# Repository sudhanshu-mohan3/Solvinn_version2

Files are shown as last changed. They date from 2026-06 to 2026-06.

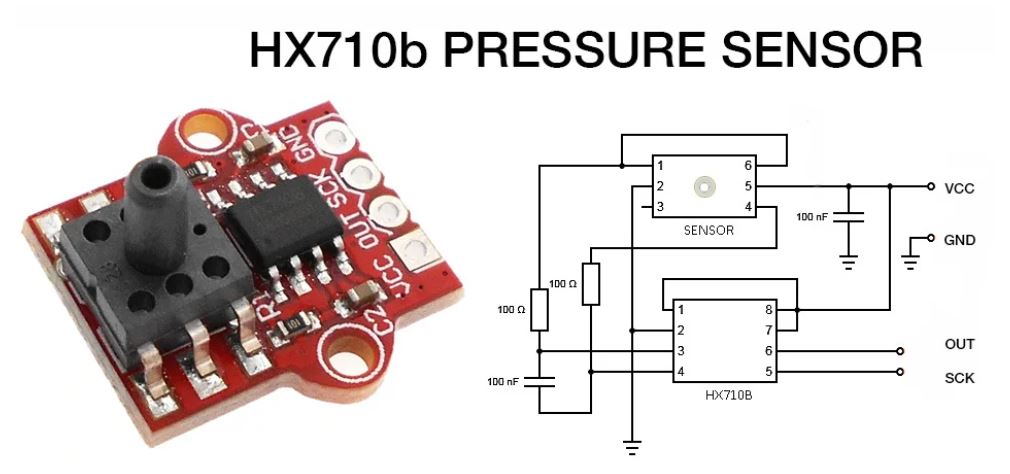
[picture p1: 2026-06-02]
hardware/Kicad/Main_PCB/Solventech_Controller/pressure-sensor-hx710b-1.snapshot.3/HX710B_2.JPG

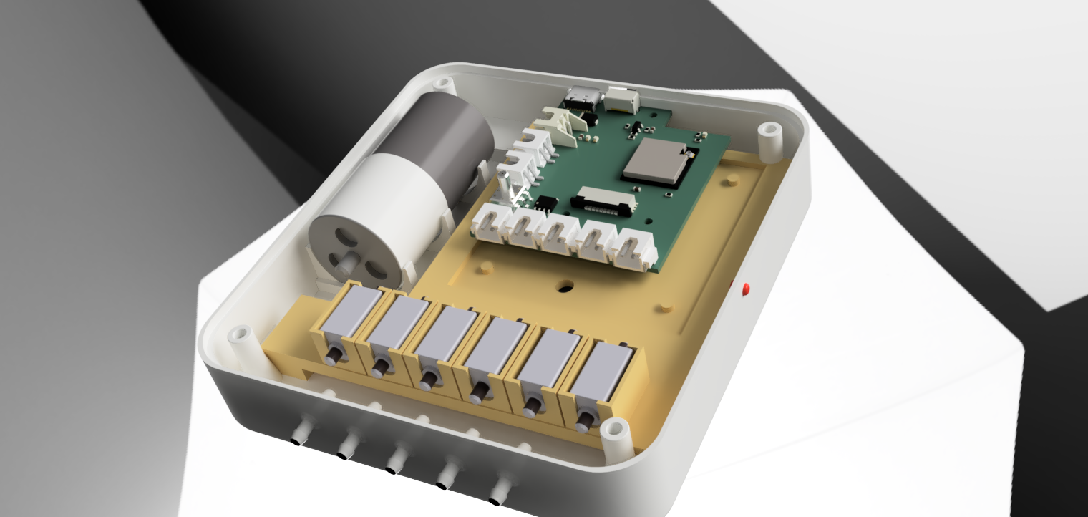
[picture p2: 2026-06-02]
hardware/Kicad/Main_PCB/Solventech_Controller/VervoFlo_2025-May-25_04-00-59PM-000_CustomizedView23459977114_png.png

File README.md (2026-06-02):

# VerveFlo

Pneumatic Compression Therapy Device firmware
ESP32-S3 · Arduino IDE

## Hardware
- ESP32-S3 Dev Module
- SH1106 OLED 128x64 (I2C)
- HX710B Pressure Sensor
- 5x Fill Solenoid Valves + 1x Release Valve (normally-open)
- 5V DC Pump Motor
- 2S 18650 Li-Ion Battery

## Pin Map
| Component | GPIO |
|---|---|
| Fill Valve 1 | 26 |
| Fill Valve 2 | 47 |
| Fill Valve 3 | 39 |
| Fill Valve 4 | 40 |
| Fill Valve 5 | 41 |
| Release Valve  | 42 |
| Pump Motor | 21 |
| HX710B Dout | 34 |
| HX710B SCK | 33 |
| LED | 3 |
| Battery ADC | 15 |
| BTN Start | 35 |
| BTN Mode | 36 |
| BTN Pressure | 37 |
| BTN Time | 48 |

## Libraries Required
- U8g2 by olikraus
- Q2HX711 by bogde (Queuetue_HX711_Library)
- WiFi / WebServer / DNSServer / Preferences — built into ESP32 core

## Board Settings
- Board: ESP32S3 Dev Module
- USB CDC On Boot: Enabled
- Partition: Default 4MB with spiffs

## Files
| File | Purpose |
|---|---|
| verveflo.ino | Main firmware — flash this |
| verveflo_hwtest.ino | Hardware test — no libraries needed |
| verveflo_pressure_cal.ino | Pressure sensor calibration |
| verveflo_valve_test.ino | Valve test with OLED |

## First Time Setup
1. Flash verveflo.ino
2. Connect phone to WiFi hotspot: VerveFlo-Setup
3. Open 192.168.4.1 → enter your WiFi password
4. Open browser → http://[device IP]
5. Serial: type zero at atmosphere
6. Serial: type selftest to verify hardware

## Serial Monitor
115200 baud · Newline line ending
Type help for full command list

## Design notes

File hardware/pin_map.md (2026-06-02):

# VerveFlo — Pin Map

Board: **ESP32-S3 Dev Module**
Pins verified against the hardware sheet (firmware v3.1).

## Valves

Valve array index order in firmware: `VALVE_PINS[6] = { 26, 47, 39, 40, 41, 42 }`

| Index | Valve | GPIO | Type | Notes |
|---|---|---|---|---|
| 0 | Fill Valve 1 | 26 | Normally-closed | Cuff 1 |
| 1 | Fill Valve 2 | 47 | Normally-closed | Cuff 2 |
| 2 | Fill Valve 3 | 39 | Normally-closed | Cuff 3 |
| 3 | Fill Valve 4 | 40 | Normally-closed | Cuff 4 |
| 4 | Fill Valve 5 | 41 | Normally-closed | Cuff 5 |
| 5 | Release Valve  | 42 | **Normally-open** | Logic inverted — energize (HIGH) to hold pressure, de-energize (LOW) to vent |

## Pump

| Component  | GPIO | Notes |
|---|---|---|
| Pump motor | 21 | Soft start via `analogWrite()` |

## Pressure sensor (HX710B)

| Signal | GPIO | Notes |
|---|---|---|
| Dout | 34 | Data out from sensor |
| SCK / CLK  | 33 | Clock |

Calibration (v3.1):
- `CALIB_M = +0.00000625` (raw increases with pressure — positive)
- `CALIB_B = 0.0`
- `CALIB_ZERO = 8388000` (atmosphere reference, re-zero with `zero` serial command)
- Overflow filter: discard raw > 16000000 (HX710B 2^24 saturation on fast release)

## Display

| Component | Interface | Notes |
|---|---|---|
| SH1106 OLED 128x64 | I2C (HW) | U8g2 library |

## Buttons (active LOW)

| Button | GPIO | Function |
|---|---|---|
| BTN Start | 35 | Play / start session |
| BTN Mode | 36 | Cycle mode |
| BTN Pressure | 37 | Cycle pressure level |
| BTN Time | 48 | Cycle session time |

## Misc

| Component | GPIO | Notes |
|---|---|---|
| LED | 3 | Status LED |
| Battery ADC | 15 | Voltage divider — battery % |

## Power

- 2S 18650 Li-Ion battery
- 5V rail for pump + valves

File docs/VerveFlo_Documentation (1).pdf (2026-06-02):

Solvin Medical Devices — VerveFlo v3.0 — Confidential

# VerveFlo

## Pneumatic Compression Therapy Device

### Complete Technical & User Documentation | v3.0

Platform | ESP32-S3 · Arduino IDE
Firmware | verveflo.ino — Single file, all-in-one
Display | SH1106 OLED 128x64 I2C
Sensor | HX710B Pressure Sensor
WiFi | AP Captive Portal + STA Mode
Company | Solvin Medical Devices

This document covers hardware setup, pin mapping, firmware architecture, WiFi provisioning, web UI, pressure sensor calibration, serial debug commands, and complete source code for the VerveFlo compression therapy device.

# Table of Contents

1. Device Overview | 3
2. Hardware & Pin Mapping | 4
3. Power Architecture | 5
4. Libraries & Setup | 6
5. Firmware Architecture | 7
6. OLED Display Screens | 9
7. WiFi Provisioning | 10
8. Web UI | 11
9. Pressure Sensor Calibration | 12
10. Serial Debug Commands | 14
11. Complete Main Firmware Code | 16
12. Hardware Test Code | 28
13. Pressure Calibration Code | 32
14. Valve Test Code | 35
15. Troubleshooting | 38

# 1. Device Overview

VerveFlo is a pneumatic sequential compression therapy device. It inflates five cuffs in a programmed sequence to push venous blood and lymphatic fluid from the distal extremity (foot/ankle) toward the proximal (thigh/groin), mimicking the natural muscle pump mechanism.

## Clinical Applications

Application | Description
DVT Prevention | Prevents deep vein thrombosis in bedridden or post-surgery patients
Lymphedema | Reduces fluid buildup in limbs via sequential lymphatic drainage
Sports Recovery | Flushes lactic acid, improves circulation after exercise
Post-op Rehab | Used after orthopedic surgeries — knee, hip replacements

## How It Works

5 cuffs wrap around the leg. They inflate sequentially distal to proximal, each cuff held at target pressure (40/70/100 mmHg) for a set time (default 8s), then deflated via a release valve before the next cuff fires. The pump builds pressure continuously while the session runs.

## Therapy Modes

Mode | Name | Sequence | Use Case
1 | Distal to Proximal | C1→C2→C3→C4→C5 | Standard venous return
2 | Proximal to Distal | C5→C4→C3→C2→C1 | Reverse lymphatic drainage
3 | Alternating | C1→C3→C5→C2→C4 | Deep vessel targeting
4 | Wave | C1→C5→C2→C4→C3 | Enhanced circulation
Custom | User Defined | Any order | Via web UI mode builder

# 2. Hardware & Pin Mapping

## Microcontroller: ESP32-S3 Dev Module

All GPIO assignments verified from hardware schematic.

## Valve & Actuator Pins

Component | Type | GPIO | Notes
Fill Valve 1 (Cuff 1) | Solenoid PWM | GPIO 26 | Foot/distal
Fill Valve 2 (Cuff 2) | Solenoid PWM | GPIO 47
Fill Valve 3 (Cuff 3) | Solenoid PWM | GPIO 39 | Mid leg
Fill Valve 4 (Cuff 4) | Solenoid PWM | GPIO 40
Fill Valve 5 (Cuff 5) | Solenoid PWM | GPIO 41 | Thigh/proximal
Release Valve | Solenoid PWM | GPIO 42 | Deflates cuffs
Pump Motor | DC Motor PWM | GPIO 21 | 5V compatible, soft start

## Sensor & Display Pins

Component | GPIO | Signal | Notes
HX710B Data (Dout) | GPIO 34 | Input | Pressure sensor data
HX710B Clock (SCK) | GPIO 33 | Output | Pressure sensor clock
OLED SH1106 | I2C HW | I2C | SDA/SCL hardware I2C
Battery ADC | GPIO 15 | ADC | 100k+100k divider, ratio 2.0
Status LED | GPIO 3 | Output | Debug indicator

## Button Pins

All buttons active LOW with internal pull-up.

Button | GPIO | Short Press | Long Press (2s)
BTN Start / Play | GPIO 35 | Start / Pause / Resume | Emergency Release + Reset
BTN Mode | GPIO 36 | Cycle Mode 1-4 | Only in READY/PAUSED state
BTN Pressure | GPIO 37 | Cycle LOW/MED/HIGH | Only in READY/PAUSED state
BTN Time | GPIO 48 | Cycle 10/20/30 min | Only in READY/PAUSED state

# 3. Power Architecture

VerveFlo uses a 2S 18650 Li-Ion battery pack (8.4V fully charged). Two separate buck converters regulate to 5V and 3.3V rails.

Rail | IC | Powers | Notes
8.4V (raw) | 2S 18650 | Buck inputs | Fully charged 8.4V, cutoff ~6V
5V | TPS54302DDCR | Valves + Pump Motor | 3A rated, min input 4.5V
3.3V | Separate buck | ESP32-S3, OLED, Buttons | Logic rail

## TPS54302DDCR Specifications

Parameter | Value
Input Voltage Range | 4.5V to 28V
Output Current | 3A continuous
Package | SOT-23-6
Switching Frequency | 570 kHz
Safe for 2S 18650? | YES — 8.4V well within range

WARNING: Motor startup current spike can damage the buck. Firmware implements PWM soft start (0 to 255 over ~1.5s, 5 counts per step every 30ms). Add 100uF capacitor across 5V output for additional spike absorption.

## Battery BMS Note

BMS may shut off prematurely due to voltage sag under motor load. This is caused by the motor startup current spike pulling the battery voltage below the BMS cutoff threshold momentarily. The PWM soft start ramp in firmware significantly reduces this. A 1000uF+ cap directly on battery output terminals eliminates it completely.

# 4. Libraries & Arduino IDE Setup

## Required Libraries

Library | Author | Install Via | Version Tested
U8g2 | olikraus | Manage Libraries → search U8g2 | 2.36.2
Queuetue_HX711_Library | bogde | Manage Libraries → search Q2HX711 | 1.0.2
WiFi | Espressif | Built into ESP32 core — no install | 3.3.8
WebServer | Espressif | Built into ESP32 core — no install | 3.3.8
DNSServer | Espressif | Built into ESP32 core — no install | 3.3.8
Preferences | Espressif | Built into ESP32 core — no install | 3.3.8

## Board Manager Setup

Add this URL in File → Preferences → Additional Boards Manager URLs:

https://raw.githubusercontent.com/espressif/arduino-esp32/gh-pages/package_esp32_index.json

Then: Tools → Board → Boards Manager → search esp32 → install esp32 by Espressif Systems

## Board Settings

Setting | Value
Board | ESP32S3 Dev Module
USB CDC On Boot | Enabled (CRITICAL for Serial Monitor)
USB Mode | Hardware CDC and JTAG
Partition Scheme | Default 4MB with spiffs
Upload Speed | 921600
CPU Frequency | 240MHz
Flash Size | 4MB

USB CDC On Boot MUST be Enabled. Without it Serial Monitor shows nothing.

# 5. Firmware Architecture

## State Machine

The entire firmware runs on a non-blocking state machine. No delay() calls in the main loop. All timing uses millis().

State | Description | LED Pattern
STATE_BOOT | Boot animation — SOLVIN logo + loading bar | Fast blink 5Hz
STATE_READY | Idle, waiting for Start button or web command | Slow blink 1Hz
STATE_RUNNING | Active session — cuffs inflating in sequence | Double pulse
STATE_PAUSED | Session paused, pressure held | Slow blink 1Hz
STATE_DEFLATE_WAIT | 2s gap between cuffs during deflation | Double pulse
STATE_RELEASING | Sequential release of all cuffs | Fast blink 5Hz

## Session Flow

STATE_READY

→ BTN_START or web /start

STATE_RUNNING

→ Open valve for cuff N (PWM ramp 0→255 over 2.5s)

→ Wait for pressure >= target (40/70/100 mmHg)

→ Hold for g_holdMs (default 8000ms)

→ Close inflate valve + open release valve

STATE_DEFLATE_WAIT

→ Wait g_deflateWaitMs (default 2000ms)

→ Close release valve

→ Advance to next cuff → back to STATE_RUNNING

→ After all 5 cuffs → check if session time expired

→ If expired → STATE_RELEASING

STATE_RELEASING

→ Release each cuff sequentially (3s each)

→ Close release valve → STATE_READY

## Valve PWM Ramp

Solenoid valves are driven via analogWrite PWM. Opening ramps 0 to 255 over 2500ms (256 steps, ~9ms per step). Closing ramps 255 to 0. This prevents voltage spikes and gives a smooth kick+hold behavior. Only one valve ramps at a time via a single ValveRamp struct.

## Motor Soft Start

Pump motor uses analogWrite with a software ramp: 5 PWM counts per step every 30ms = approximately 1.5 seconds from 0 to full speed. This prevents inrush current spikes that kill the buck converter.

## Pressure Reading

// Formula:

mmHg = CALIB_M * (raw - CALIB_ZERO) + CALIB_B

// Current calibrated values:

const float CALIB_M = 0.00000625f; // positive — raw increases with pressure

const float CALIB_B = 0.0000f;

long | CALIB_ZERO = 8388000L; | // raw value at atmosphere (0 mmHg)

// Overflow filter: HX710B saturates to ~16777216 during fast release

if (raw > 16000000L || raw < 0) return last_good_value;

## Key Timing Parameters

Parameter | Default | Serial Command | Range
Hold per cuff | 8000ms | hold N (seconds) | 2-60s
Deflate gap | 2000ms | gap N (seconds) | 1-15s
Release per cuff | 3000ms | Not configurable | Fixed
Valve ramp time | 2500ms | Not configurable | Fixed
Motor ramp time | ~1500ms | Not configurable | Fixed
Pressure sample | 200ms | Not configurable | Fixed
Display update | 250ms | Not configurable | Fixed
Battery read | 10s | Not configurable | Fixed

# 6. OLED Display Screens

Display: SH1106 128x64 I2C. All screens include 4-bar battery icon top-right.

Screen | Content
Boot — SOLVIN Logo | Letters S-O-L-V-I-N appear one by one. "Medical Devices" fades in. ~1 second.
Boot — VerveFlo Loading | "VerveFlo / Compression Therapy". Loading bar fills with status messages: Initialising / Calibrating / Loading modes / Connecting WiFi / Ready. Shows WiFi IP or AP name at bottom when done.
READY | MODE N + mode name. PRES LOW/MED/HIGH. TIME 10m/20m/30m. WiFi IP address. Blinking [PRESS START] prompt.
RUNNING | Large pressure number (mmHg) + target. Countdown timer mm:ss. Mode name. 5 animated circles — active cuff pulses (filled disc alternates with outline at 80ms interval). Thin pressure bar with amber target marker. 4-bar battery.
DEFLATING | Same as RUNNING but header shows DEFLATING instead of RUNNING.
PAUSED | Blinking large PAUSED text. Press START to resume. Mode/pressure/time settings reminder.
RELEASING | Progress bar filling as each cuff releases. Cuff X/5 counter. Animated circles. Please wait...

# 7. WiFi Provisioning

VerveFlo manages WiFi credentials automatically with zero configuration needed by the user.

## First Boot — AP Mode

1. No saved WiFi credentials in flash
2. ESP32 starts hotspot: "VerveFlo-Setup" (open, no password)
3. DNS server redirects ALL traffic to 192.168.4.1 (captive portal)
4. User connects phone to "VerveFlo-Setup"
5. Browser auto-opens (captive portal) OR user opens 192.168.4.1
6. Setup page shows WiFi scan list
7. User taps network → enters password → taps CONNECT & SAVE
8. Credentials saved to ESP32 flash (Preferences library)
9. Device restarts → connects to home WiFi
10. IP address shown on OLED and Serial Monitor

## Subsequent Boots — STA Mode

1. Reads saved SSID + password from flash
2. Connects to home WiFi (24 attempts × 500ms = 12 second timeout)
3. If connected → shows IP on OLED → WebServer starts on port 80
4. If failed → falls back to AP mode automatically

## Reset WiFi

Serial command: wificlear

Web endpoint: http://<IP>/wificlear

Effect: Clears saved credentials, restarts device in AP mode

## Access Points

Endpoint | Method | Description
/ | GET | Serve HTML web UI
/status | GET | JSON status — polled every 500ms by UI
/start | GET | Start session
/pause | GET | Pause or resume session
/stop | GET | Stop + release all cuffs
/release | GET | Emergency release
/set_pressure | GET | ?level=0/1/2 (LOW/MED/HIGH)
/set_time | GET | ?idx=0/1/2 (10/20/30 min)
/set_mode | GET | ?mode=0-3

/set_timings | GET | ?hold_ms=N&gap_ms=N
/scan | GET | Scan WiFi networks (AP mode setup)
/savewifi | GET | ?ssid=X&pass=Y — save credentials
/wificlear | GET | Clear WiFi, restart in AP mode

# 8. Web UI

The web UI is embedded directly in firmware as a PROGMEM string — no SPIFFS upload needed. Served at http://[device-IP]/ Works in any phone or laptop browser on the same WiFi network.

## Features

Feature | Description
Live Status | State chip, animated cuff circles, pressure bar, countdown timer
4-Bar Battery | Visual battery indicator synced with device
START/PAUSE/RESUME | Single morphing button changes color and label with state
STOP + RELEASE | Separate stop and emergency release buttons
Pressure Target | LOW/MED/HIGH chips (40/70/100 mmHg)
Session Time | 10/20/30 min chips
Hold/Gap Sliders | Adjustable inflate hold (3-30s) and deflate gap (1-15s)
Mode Builder | M1-M4 presets + custom sequence builder (tap cuffs in order)
WiFi Setup Page | Shown in AP mode — scan networks, enter password, save
Demo Mode | Works without device connected — simulates session for UI testing
Auto Connect | Automatically connects to device IP from URL hostname

## How to Access

1. Connect phone/laptop to same WiFi as VerveFlo
2. Open Serial Monitor → type "ip" → note the IP address

(also shown on OLED ready screen)

3. Open browser → type: http://192.168.x.x
4. UI loads automatically
5. Type IP in CONNECT field → tap CONNECT → status goes LIVE

# 9. Pressure Sensor Calibration

Sensor: HX710B connected to GPIO 34 (Dout) and GPIO 33 (SCK).

## Key Findings from Hardware Testing

Finding | Detail
Raw direction | Raw value INCREASES with pressure (not decreases as initially assumed)
Atmosphere raw | Approximately 8,388,000 at 0 mmHg
Pressure raw | Increases toward ~8,900,000 at higher pressures
Overflow | ~16,777,216 (2^24) during fast pressure release — must be filtered
CALIB_M sign | Positive (+0.00000625) because raw goes up with pressure

## Calibration Formula

mmHg = CALIB_M * (raw - CALIB_ZERO) + CALIB_B

Where:

raw | = HX710B raw reading

CALIB_ZERO = raw value at 0 mmHg (atmosphere)

CALIB_M | = slope (positive for this sensor)
CALIB_B | = offset (0 after proper zeroing)

## Current Calibration Values

const float CALIB_M | = 0.00000625f; | // slope — positive
const float CALIB_B | = 0.0000f; | // offset
long | CALIB_ZERO = 8388000L; | // atmosphere baseline

// UPDATE this after running 'zero' command

## Calibration Procedure

STEP 1: Upload verveflo_pressure_cal.ino (see Section 13)
STEP 2: Open Serial Monitor at 115200 baud, Newline line ending
STEP 3: At atmosphere (open air, no pressure applied):

Type: z

Result: "Zero set to raw=8XXXXXXX"

Note this number → put in CALIB_ZERO

STEP 4: Build pressure with reference gauge connected:

Type: pump on

Type: ps | (watch live pressure stream)
Type: pump off | (stop at stable known pressure)

STEP 5: With reference gauge at e.g. 50 mmHg:

Type: c 50

Result: prints CALIB_M and CALIB_B values

STEP 6: Verify:

Type: ps (should read ~50 mmHg)

Type: pump on / pump off to verify range

STEP 7: Copy values to verveflo.ino:

const float CALIB_M = [value from step 5];

const float CALIB_B = [value from step 5];

long CALIB_ZERO = [value from step 3];

## Live Zero (without reflashing)

In main firmware serial monitor:

Type: zero

Effect: Samples 16 readings at current pressure, sets CALIB_ZERO live

Use: Run at atmosphere before each session if readings drift

# 10. Serial Debug Commands

Connect USB cable. Open Arduino IDE Serial Monitor. Set baud rate to 115200. Set line ending to Newline. Type command and press Enter.

## Session Control

Command | Action
start | Start therapy session (only in READY state)
pause | Pause session (type again to resume)
stop | Stop session + sequential cuff release
release | Emergency release all cuffs immediately

## Status & Readings

Command | Output
status | Full system dump — state, pressure, battery, mode, timing, WiFi IP
pressure | Current pressure in mmHg
battery | Battery voltage, percent, bar count
valves | All 6 valve states — IDLE / RAMP UP / RAMP DN
buttons | Current button pin states HIGH/LOW
pins | All output pin states
ip | Current WiFi IP address or AP mode info
zero | Set pressure zero at current atmosphere reading

## Direct Hardware Control (Debug)

Command | Action
v1 on | Cuff 1 valve GPIO26 instant ON (255 PWM)
v1 off | Cuff 1 valve GPIO26 OFF
v1 open | Cuff 1 valve PWM ramp open (2.5s ramp)
v1 close | Cuff 1 valve PWM ramp close
v1 128 | Set cuff 1 to specific PWM duty (0-255)
v2-v5 on/off | Same as v1 for cuffs 2-5
vr on/off | Release valve GPIO42 ON/OFF
pump on | Pump motor ON (via soft start ramp)
pump off | Pump motor OFF (via soft stop ramp)
motor 128 | Set motor to specific PWM duty 0-255 (with ramp)
alloff | Immediately kill pump + all 6 valves

## Diagnostic Tests

Command | Action
selftest | Full auto test: LED blink, battery, pressure sensor, pump 2s, all valves 1s each
pstream | Live pressure stream with bar graph — any key to stop
ptest | Pump ON + watch pressure build to target — auto stops at target
vsweep | Open each inflate valve 2s in sequence — any key to stop

## Settings (READY or PAUSED state only)

Command | Action
mode 1-4 | Set therapy mode 1=Distal 2=Proximal 3=Alternating 4=Wave
pset 0 | Pressure target LOW 40 mmHg
pset 1 | Pressure target MED 70 mmHg
pset 2 | Pressure target HIGH 100 mmHg
time 0 | Session duration 10 minutes
time 1 | Session duration 20 minutes
time 2 | Session duration 30 minutes
hold N | Cuff inflate hold time in seconds (2-60)
gap N | Deflate gap between cuffs in seconds (1-15)
led on | Force LED solid ON
led off | Force LED OFF
led blink | Blink LED 5x to confirm GPIO3 working
led auto | Restore automatic LED pattern
wificlear | Clear saved WiFi credentials, restart in AP mode
reboot | Software restart
help | Print full command list

# 11. Complete Main Firmware — verveflo.ino

Single .ino file. Place in folder named verveflo/. Update WIFI_SSID and WIFI_PASS with your network credentials before flashing, or leave blank and use the captive portal WiFi setup on first boot.

NOTE: Full code is too large to reproduce here in its entirety. Key sections are shown below. The complete file was provided during development and is saved as verveflo.ino.

## File Header & Includes

#include <Arduino.h>

#include <WiFi.h>

#include <WebServer.h>

#include <DNSServer.h>

#include <Preferences.h>

#include <U8g2lib.h>

#include <Wire.h>

#include <Q2HX711.h>

// *** CHANGE THESE TO YOUR WIFI CREDENTIALS ***

const char* WIFI_SSID = "YourWiFiName";

const char* WIFI_PASS = "YourWiFiPassword";

## Pin Definitions

const uint8_t VALVE_PINS[6] = { 26, 47, 39, 40, 41, 42 };

#define RELEASE_VALVE_IDX 5

#define NUM_INFLATE_VALVES 5

#define PUMP_PIN | 21

#define LED_PIN | 3

#define HX_DATA | 34

#define HX_CLK | 33

#define BATT_PIN | 15

#define BTN_START | 35

#define BTN_MODE | 36

#define BTN_PRESS | 37

#define BTN_TIME | 48

## Calibration Values

const float CALIB_M | = 0.00000625f; | // UPDATE after calibration
const float CALIB_B | = 0.0000f;
long | CALIB_ZERO = 8388000L; | // UPDATE after running zero command

float g_pressure = 0.0f;

## System State Enum

enum SystemState {

STATE_BOOT,

STATE_READY,

STATE_RUNNING,

STATE_PAUSED,

STATE_RELEASING,

STATE_DEFLATE_WAIT

};

SystemState g_sysState = STATE_BOOT;

## Session Settings

const float | PRESSURE_LEVELS[] = { 40.0f, 70.0f, 100.0f };
const char* | PRESSURE_LABELS[] = { "LOW", "MED", "HIGH" };
const uint16_t TIME_OPTIONS[] | = { 10, 20, 30 };
const char* | TIME_LABELS[] | = { "10m", "20m", "30m" };

const uint8_t MODE_SEQS[4][5] = {

{ 0,1,2,3,4 }, | // Mode 1: Distal to Proximal
{ 4,3,2,1,0 }, | // Mode 2: Proximal to Distal
{ 0,2,4,1,3 }, | // Mode 3: Alternating
{ 0,4,1,3,2 } | // Mode 4: Wave

};

uint8_t g_pressureIdx | = 1; | // default MED
uint8_t g_timeIdx | = 0; | // default 10 min
uint8_t g_mode | = 0; | // default Mode 1
uint32_t g_holdMs | = 8000UL;

uint32_t g_deflateWaitMs = 2000UL;

## Pressure Read Function

float readPressure() {

long raw = hx711.read();

// Filter HX710B overflow during fast pressure release

if (raw > 16000000L || raw < 0) {

return g_pressure; // return last good value

}

long adj | = raw - CALIB_ZERO;
float mmhg | = CALIB_M * (float)adj + CALIB_B;

return constrain(mmhg, 0.0f, 200.0f);

}

## Motor Soft Start

// Global motor state

uint8_t | g_motorDuty | = 0;
uint8_t | g_motorTarget = 0;
bool | g_motorRamping = false;
unsigned long g_motorRampT | = 0;

void setPump(bool on) {

g_motorTarget = on ? 255 : 0;

g_motorRamping = true;

g_motorRampT = millis();

Serial.printf("[PUMP] %s -> ramping\n", on ? "ON" : "OFF");

}

void updateMotorRamp() {

if (!g_motorRamping) return;

unsigned long now = millis();

if (now - g_motorRampT < 30) return; // 30ms per step

g_motorRampT = now;

if (g_motorDuty < g_motorTarget)

g_motorDuty = min((int)g_motorDuty + 5, (int)g_motorTarget);

else if (g_motorDuty > g_motorTarget)

g_motorDuty = max((int)g_motorDuty - 5, (int)g_motorTarget);

else { g_motorRamping = false; }

analogWrite(PUMP_PIN, g_motorDuty); // analogWrite only, no ledc

}

## Valve PWM Ramp

#define RAMP_DURATION_MS | 2500UL

#define RAMP_STEPS | 256

#define RAMP_STEP_INTERVAL (RAMP_DURATION_MS / RAMP_STEPS) // ~9ms per step

void startOpenValve(uint8_t idx) {

g_ramp = {true, true, 0, idx, millis()};

analogWrite(VALVE_PINS[idx], 0);

}

void startCloseValve(uint8_t idx) {

// Start at 255 ramp DOWN — prevents uint8_t underflow bug

g_ramp = {true, false, 255, idx, millis()};

analogWrite(VALVE_PINS[idx], 255);

}

void updateRamp() {

if (!g_ramp.active) return;

unsigned long now = millis();

if (now - g_ramp.lastStepTime < RAMP_STEP_INTERVAL) return;

g_ramp.lastStepTime = now;

if (g_ramp.opening) {

if (g_ramp.duty < 255) analogWrite(VALVE_PINS[g_ramp.valveIdx], ++g_ramp.duty);

else g_ramp.active = false;

} else {

if (g_ramp.duty > 0) analogWrite(VALVE_PINS[g_ramp.valveIdx], --g_ramp.duty);

else { analogWrite(VALVE_PINS[g_ramp.valveIdx], 0); g_ramp.active = false; }

}

}

## Main Loop Structure

void loop() {

unsigned long now = millis();

server.handleClient(); | // WiFi web requests

if (g_apMode) dnsServer.processNextRequest(); // AP captive portal

handleSerial(); | // Serial commands

if (now - g_lastBattTime >= BATT_INTERVAL_MS) { readBattery(); }

if (g_sysState == STATE_BOOT) {

// Non-blocking boot animation

if (now - g_bootStepTime >= BOOT_STEP_MS) { drawBootScreen(); }

updateLED(); return;

}

if (now - g_lastPressRead >= PRESS_MS) { g_pressure = readPressure(); }

pollButtons();

handleEvents();

updateRamp();

updateMotorRamp(); | // Motor soft start tick

if (g_sysState == STATE_RUNNING) updateSession();

if (g_sysState == STATE_RELEASING || g_sysState == STATE_DEFLATE_WAIT)

updateReleaseSequence();

if (now - g_lastDisplay >= DISPLAY_MS) { updateDisplay(); }

updateLED();

}

# 12. Hardware Test Code — verveflo_hwtest.ino

Standalone test sketch. NO libraries needed (no U8g2, no Q2HX711). Uses raw bit-bang HX710B read. Upload separately to verify hardware before flashing main firmware.

## Commands

Command | Action
selftest | Full auto test: LED, battery, pressure sensor, pump 2s, all valves 1s each
led | Blink LED 5x on GPIO 3
pump on | Pump motor ON GPIO 21
pump off | Pump motor OFF
v1 on/off | Fill valve 1 GPIO 26
v2 on/off | Fill valve 2 GPIO 47
v3 on/off | Fill valve 3 GPIO 39
v4 on/off | Fill valve 4 GPIO 40
v5 on/off | Fill valve 5 GPIO 41
vr on/off | Release valve GPIO 42
alloff | Everything OFF immediately
pressure | Single raw pressure read + calculated mmHg
pstream | Live pressure stream with bar graph (any key stops)
battery | Battery ADC raw + voltage + percent
pins | Print all output pin states
buttons | Print all button pin states (press button while typing)

## Recommended Debug Workflow

selftest | <- Run first. Checks every component automatically.
| Outputs PASS/FAIL per component.
led | <- Confirm GPIO3 working. Should blink 3x.
pump on | <- Hear motor? If not: check GPIO21, check 5V rail, check wiring

pump off

v1 on | <- Hear valve click? If not:
1. Check GPIO26 HIGH with multimeter
2. Check driver circuit (MOSFET/transistor)
3. Check 5V rail while valve on

v1 off

(repeat v2-v5, vr)

pstream | <- Watch raw values. If all same number → sensor wiring issue

pump on | <- Watch values change while pumping

pump off

battery | <- Check voltage reading. If 0: check GPIO15 divider

## Code Snippet — selftest function

void selfTest() {

// 1. LED

for(uint8_t i=0;i<6;i++){ digitalWrite(LED_PIN,i%2==0); delay(250); }

digitalWrite(LED_PIN,LOW);

// 2. Battery

readBattery();

Serial.printf("Battery: %.2fV %d%%\n", g_battV, g_battPct);

// 3. Pressure sensor

long raw = readHX710B();

float mmhg = rawToMmHg(raw);

Serial.printf("Pressure: %.2f mmHg (raw=%ld)\n", mmhg, raw);

// 4. Pump motor (2s)

digitalWrite(PUMP_PIN, HIGH); delay(2000);

digitalWrite(PUMP_PIN, LOW);

// 5. Each inflate valve (1s each)

for(uint8_t i=0;i<5;i++){

digitalWrite(VALVE_PINS[i], HIGH); delay(1000);

digitalWrite(VALVE_PINS[i], LOW); delay(200);

}

// 6. Release valve (1s)

digitalWrite(VALVE_PINS[5], HIGH); delay(1000);

digitalWrite(VALVE_PINS[5], LOW);

}

# 13. Pressure Calibration Code — verveflo_pressure_cal.ino

Uses Q2HX711 library. Provides live streaming, zeroing, and two-point calibration. Run this before first use to get accurate CALIB_M and CALIB_ZERO values.

## Commands

Command | Action
r | Single raw reading (average of 8)
s | Stream raw values with adj and mmHg columns
z | Zero/Tare — set current reading as 0 mmHg baseline
c 50 | Calibrate at known pressure (replace 50 with gauge reading)
t | Show current CALIB_M, CALIB_B, CALIB_ZERO values
p | Single mmHg reading with current calibration
ps | Live mmHg stream with bar graph
pump on/off | Control pump to build pressure
v1 on/off | Bleed pressure via cuff 1 valve
vr on/off | Bleed via release valve

## Full Calibration Procedure

PREREQUISITE: Have a reference pressure gauge connected to the same air line.

1. Upload verveflo_pressure_cal.ino
2. Open Serial Monitor: 115200 baud, Newline line ending
3. AT ATMOSPHERE (nothing pressurized, open to air):

Type: z

Serial prints: "Zero set to raw=8XXXXXXX"

NOTE THIS NUMBER → this is your CALIB_ZERO

4. BUILD PRESSURE:

Type: pump on

Type: ps | (watch bar graph climb)

Type: pump off (stop when gauge reads a known value e.g. 50 mmHg)

5. CALIBRATE:
Type: c 50 | (use whatever your reference gauge reads)

Serial prints:

Known | : 50.00 mmHg
Raw | : 8XXXXXXX

Adjusted : XXXXXXX

CALIB_M = 0.00000625f

CALIB_B = 0.0000f

6. VERIFY:

Type: ps

Watch values — should match reference gauge at various pressures

7. COPY TO MAIN FIRMWARE:

In verveflo.ino find:

const float CALIB_M | = -0.00000625f; // OLD
long | CALIB_ZERO = 0L; | // OLD

Replace with values from step 5 and step 3:

const float CALIB_M | = 0.00000625f; // NEW (positive)
const float CALIB_B | = 0.0000f;
long | CALIB_ZERO = 8388000L; | // NEW (from step 3)

## Important Notes

CALIB_M must be POSITIVE for this sensor — raw increases with pressure. CALIB_ZERO must be set at true atmosphere (pump off, valves open, all pressure released). Running zero command with pressure still in system gives wrong baseline.

## Debug Output Format

// readPressure() with debug enabled outputs:

[PRESS] raw=8880956 zero=8388000 adj=492956 mmhg=3.08 result=3.08

// Explanation:

raw | = HX710B raw 24-bit value
zero | = CALIB_ZERO (atmosphere baseline)
adj | = raw - zero (pressure delta)
mmhg | = CALIB_M * adj + CALIB_B (calculated)

result = after constrain(0-200 mmHg)

// If result=0 but mmhg is negative → CALIB_M sign wrong or zero not set

// If raw=0 → sensor not responding → check wiring

// If raw=16776xxx → overflow during fast release → normal, filtered

# 14. Valve Test Code — verveflo_valve_test.ino

Uses U8g2 library. Tests all 6 valves with live OLED feedback. OLED shows filled box = valve ON, outline box = valve OFF. Updates in real time as commands are typed.

## Commands

Command | Action
v1 on/off | Fill valve 1 GPIO 26 — OLED C1 box fills
v2 on/off | Fill valve 2 GPIO 47
v3 on/off | Fill valve 3 GPIO 39
v4 on/off | Fill valve 4 GPIO 40
v5 on/off | Fill valve 5 GPIO 41
vr on/off | Release valve GPIO 42 — OLED REL box fills
all on | All 6 valves ON simultaneously
all off | All 6 valves OFF
sweep | Auto open each valve 2s in sequence with OLED animation
status | Print all valve states + GPIO readings

## OLED Display Layout

Row 1: VALVE TEST header

Row 2-3: V1[C1/G26] V2[C2/G47] V3[C3/G39] <- filled = ON

Row 4-5: V4[C4/G40] V5[C5/G41] VR[REL/G42] <- outline = OFF

Row 6: "N/6 ON -- serial cmd"

Box filled = valve ON (solenoid energized)

Box outline = valve OFF (solenoid de-energized)

## Use This When

Symptom | Test to run
Valve not clicking | sweep — confirms which valves respond
Cuff not inflating | v1 on → check GPIO HIGH + listen for click
All valves dead | all on — if nothing → check 5V rail
Specific valve not working | vN on individually → check driver circuit for that valve
Release not deflating | vr on → listen for click on release valve GPIO42
Valve stuck open | alloff → confirms firmware can control all pins

# 15. Troubleshooting

## Serial Monitor Shows Nothing

Check | Fix
USB CDC On Boot setting | Tools → USB CDC On Boot → Enabled → re-upload
Baud rate | Set to 115200 in Serial Monitor
Wrong COM port | Tools → Port → select JTAG/CDC port
ESP32-S3 needs time | Add delay(2000) at start of setup()

## Pressure Always Shows 0

Symptom | Cause | Fix
raw=0 always | Sensor not connected | Check DATA=GPIO34 CLK=GPIO33 VCC GND
mmhg negative, result=0 | CALIB_M is negative, raw going up Change CALIB_M to positive
CALIB_ZERO wrong | Zero run under pressure | Release all pressure, type zero again
raw=16777216 always | Overflow state | Power cycle sensor, check wiring
raw changes but mmhg flat CALIB_ZERO too high | | Re-run zero at true atmosphere

## Buck Converter Overheating

Cause | Fix
Motor startup spike | Firmware motor soft start (updateMotorRamp) — verify it is in loop()
Cap missing | Add 100uF-2200uF across 5V output terminals
Wrong output voltage | Measure output — should be 5.0-5.2V, not higher
Too much load | Separate motor onto its own power path (MOSFET from battery)

## BMS Shuts Off Under Load

Cause | Fix
Voltage sag from motor spike | Add 1000uF+ cap directly on battery output terminals
BMS cutoff too high | Check BMS cutoff voltage — should be 5.4-5.6V for 2S
Single cell battery | Ensure 2S (two cells in series) for 8.4V — single cell too low
PWM not working | Type motor 50 in serial — confirm slow ramp, not instant full speed

## WiFi Not Connecting

Symptom | Fix
No VerveFlo-Setup hotspot | Type wificlear in serial → restarts in AP mode
Captive portal not opening | Manually open 192.168.4.1 in browser

Saved WiFi fails to connect | Type wificlear → redo setup with correct password
IP not showing on OLED | Type ip in serial monitor
UI shows OFFLINE | Check IP in connect field — must match device IP exactly

## Valves Not Responding

Symptom | Fix
No click sound | Check driver circuit (MOSFET gate voltage), check 5V rail
Some valves work | Check specific GPIO pin HIGH with multimeter, check driver for that channel
Valve stuck open | Type vN off in serial, check if GPIO goes LOW
PWM ramp not working | Type v1 on for instant ON — if works, ramp issue
All valves dead | Check 5V rail voltage under load, check common GND

VerveFlo v3.0 — Solvin Medical Devices — Technical Documentation

For support contact the development team. Document generated automatically from firmware v3.0.

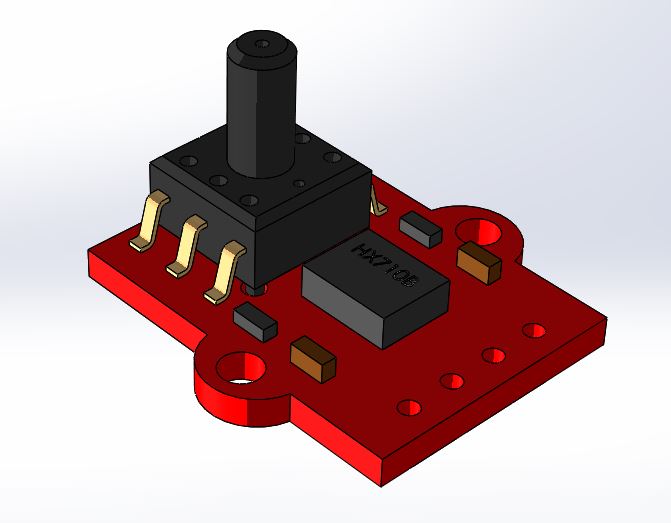
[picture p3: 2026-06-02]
hardware/Kicad/Main_PCB/Solventech_Controller/pressure-sensor-hx710b-1.snapshot.3/HX710B.JPG

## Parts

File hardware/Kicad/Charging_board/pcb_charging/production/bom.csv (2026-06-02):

Designator | Footprint | Quantity | Value | LCSC Part #
C1, C12, C13, C14, C3, C4 | 0805 | 6 | 100nf
C2 | 0805 | 1 | 1uF_0805
D1 | D_SMA | 1 | SS34
D3 | D_SMA | 1 | SS14
D7 | 0805 | 1 | RED LED
D8 | 0805 | 1 | GREEN LED
J1, J5 | Solder_pad2 | 2 | JST-S2B-XH_Sideentry
J2 | USB_C_Receptacle_XKB_U262-16XN-4BVC11 | 1 | USB_C_Receptacle_USB2.0_16P
L1 | LMLP07A7M1R0DTAS_AVX | 1 | 10uh
Q2 | SOIC-8_3.9x4.9mm_P1.27mm | 1 | IRF7832
R1 | R_2512 | 1 | 50mohm_2512
R2, R4 | 0603 | 2 | 2.2k
R3, R5 | 0603 | 2 | 5.1K
SW1 | SW_Slide_SPDT_Angled_CK_OS102011MA1Q | 1 | SW_Slide_SPDT_Straight_CK_OS102011MS2Q
TP1 | TestPoint_Pad_D1.0mm | 1 | TestPoint
U2 | SOIC-8_3.9x4.9mm_P1.27mm | 1 | CN3302

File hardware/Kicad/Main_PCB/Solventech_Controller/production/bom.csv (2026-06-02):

Designator | Footprint | Quantity | Value | LCSC Part #
C1 | 0603 | 1 | 10nf
C10, C21, C26, C3 | 0805 | 4 | 0.1uF_0805
C11, C22, C25, C27, C4, C6 | 0805 | 6 | 1uF_0805
C2, C20 | CP_EIA-2012-15_AVX-P | 2 | 100uF-35V | CP_EIA-2012-15_AVX-P
C24, C5 | 0805 | 2 | 10uF_0805
C8 | CP_Elec_5x3 | 1 | 100uF_50V_THT_Electrolytic
C9 | 0603 | 1 | 10uf
D1, D13, D14, D15, D16 | 0603 | 5 | RED | C71911
D10, D11, D12, D4, D6, D7, D8, D9 | D_SMA | 8 | SS14 | SS14
J1 | FFC_Connector_8pos | 1 | Conn_01x08_Socket
J12 | JST_PH_S2B-PH-SM4-TB_1x02-1MP_P2.00mm_Horizontal | 1 | JST-B2B-XH_Topentry | B3B-XH_Topentry
J13 | JST_XH_B3B-XH-AM_1x03_P2.50mm_Vertical | 1 | Conn_01x03_Pin | B3B-XH-AM_1x03
J2 | JST_PH_S2B-PH-SM4-TB_1x02-1MP_P2.00mm_Horizontal | 1 | JST-B2B-XH_Topentry
J5 | USB_C_Receptacle_XKB_U262-16XN-4BVC11 | 1 | USB_C_Receptacle_USB2.0_16P | Receptacle_XKB_U262-16XN-4BVC11
L1, L2 | LMLP07A7M1R0DTAS_AVX | 2 | BMRF00060630100MA1 | BMRF00060630100MA1
R1, R4, R5 | 0603 | 3 | 1K
R10, R11, R3, R35, R38 | 0603 | 5 | 500R | C25905
R12, R36 | 0603 | 2 | 3K3_0603
R13, R23, R24, R25, R26, R27, R28, R29 | 0603 | 8 | 33R
R14, R6 | 0805 | 2 | 1K_0805
R16, R7 | 0603 | 2 | 511K_0603
R17, R18, R32, R37 | 0603 | 4 | 10K_0603
R19 | 0603 | 1 | 2K2_0603
R2 | 0603 | 1 | 10K
R20 | 0603 | 1 | 1K_0603
R21, R22 | 0603 | 2 | 1.2K
R30, R31 | 0603 | 2 | 4.7K
R33, R8 | 0603 | 2 | 105K_0603
R34, R9 | 0603 | 2 | 100K_0603
SW1, SW2 | SKRPABE010 | 2 | SW_Push | C720477
U1 | ESP32-S2-MINI-1 | 1 | ESP32-S3-MINI-1 | ESP32-S3-MINI-1
U10, U11, U3, U5, U6, U7, U8, U9 | SOT-23 | 8 | AO3400 | AO3400
U12 | SOIC-8_3.9x4.9mm_P1.27mm | 1 | HX710B | HX710B
U14, U2 | SOT-23-6 | 2 | TPS54302DDCR | TPS54302DDCR
U4 | SOT-23-5 | 1 | AP2127K-ADJTRG1 | AP2127K-ADJTRG1

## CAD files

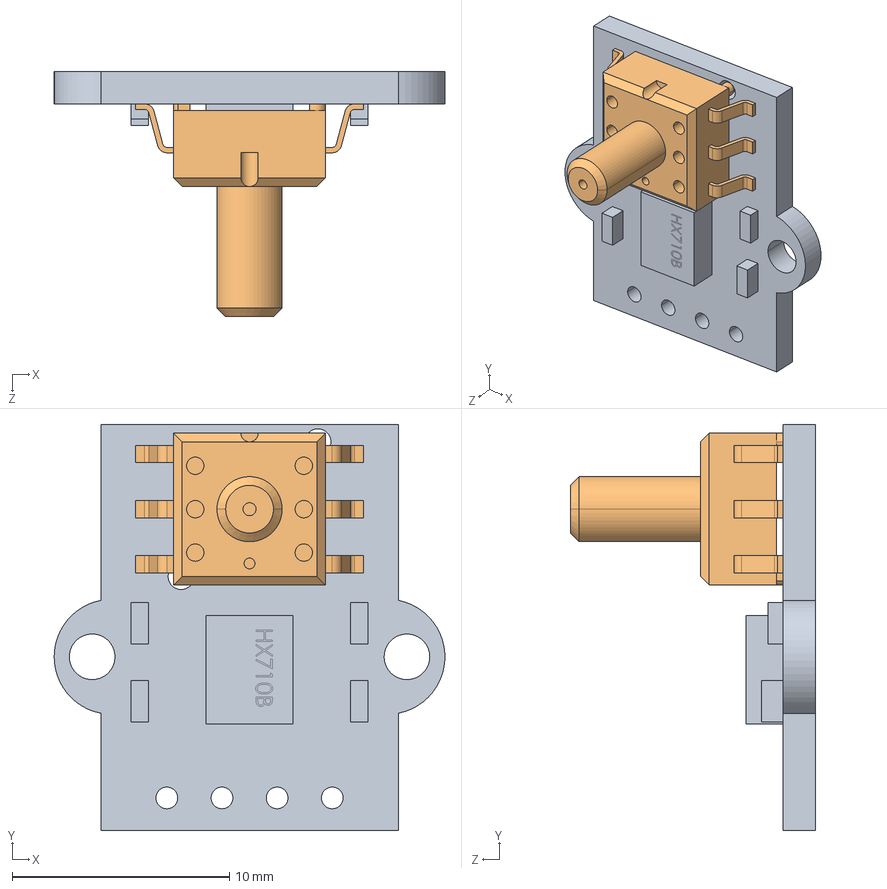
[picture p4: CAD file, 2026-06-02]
hardware/Kicad/Main_PCB/Solventech_Controller/pressure-sensor-hx710b-1.snapshot.3/pressure_sensor_assy_HX710B.STEP
18.0 x 18.7 x 11.3 mm
pressure_sensor_pcb_HX710B
MPS-3117_По умолчанию

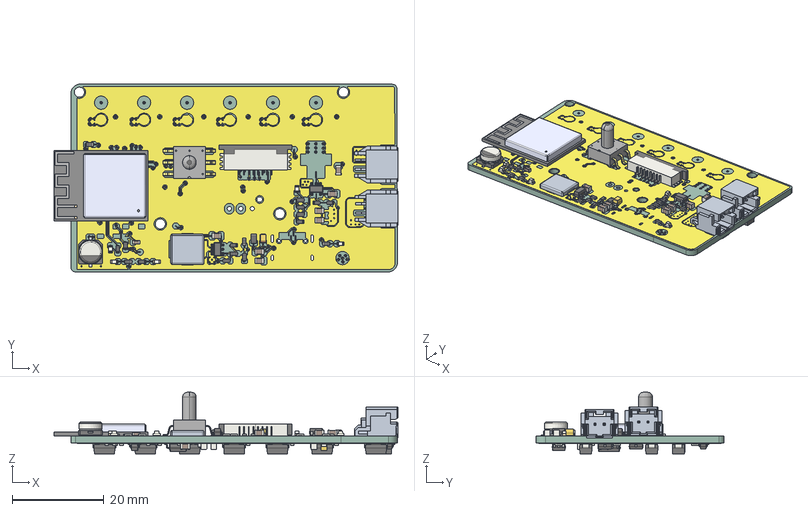
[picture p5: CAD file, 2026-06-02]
hardware/Kicad/Main_PCB/Solventech_Controller/Main2.step
74.9 x 40.9 x 13.4 mm
C_0805_2012Metric x 12
R_0603_1608Metric x 31
CP_Elec_5x3
ESP32-S3-MINI-1-N8--3DModel-STEP-510211
C_0603_1608Metric x 2
SOT-23-5 x 3
TE_84952-8_1x08-1MP_P1.0mm_Horizontal
CP_EIA-2012-15_AVX-P x 2
Main2 1.21.1
LED_0603_1608Metric x 5
R_0805_2012Metric x 2
MPS20N0040D-S--3DModel-STEP-514995
SOT-23 x 8
D_SMA x 8
SOIC-8_3.9x4.9mm_P1.27mm
Solventech_Controller_copper
Solventech_Controller_via
Solventech_Controller_PCB

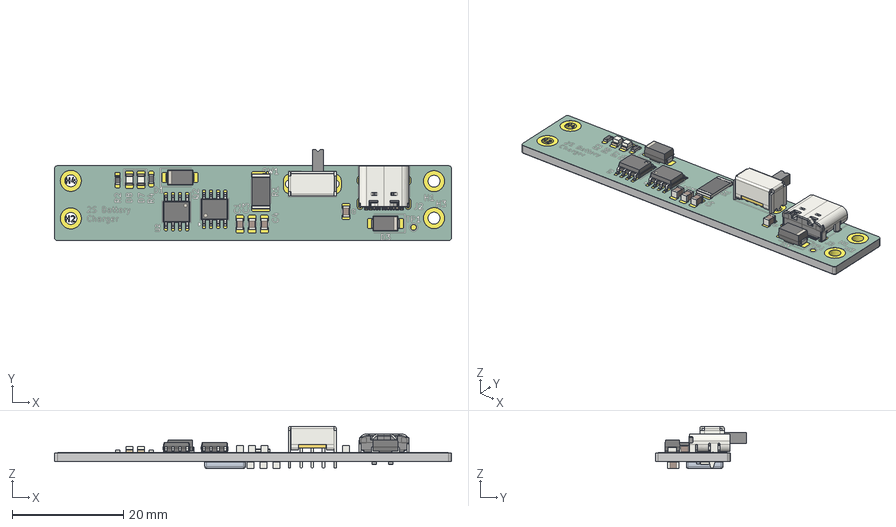
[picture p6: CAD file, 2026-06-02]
hardware/Kicad/Charging_board/pcb_charging/secondary_pcb_charging.step
71.3 x 16.4 x 7.63 mm
C_0805_2012Metric x 7
D_SMA x 2
LED_0805_2012Metric x 2
SW_Slide_SPDT_Angled_CK_OS102011MA1Q
USB_C_Receptacle_GCT_USB4105-xx-A_16P_TopMnt_Horizontal
SOIC-8_3.9x4.9mm_P1.27mm x 2
R_0603_1608Metric x 4
R_2512_6332Metric
secondary_pcb_charging 1.21.1
secondary_pcb_charging_copper
secondary_pcb_charging_silkscreen
secondary_pcb_charging_soldermask
secondary_pcb_charging_PCB

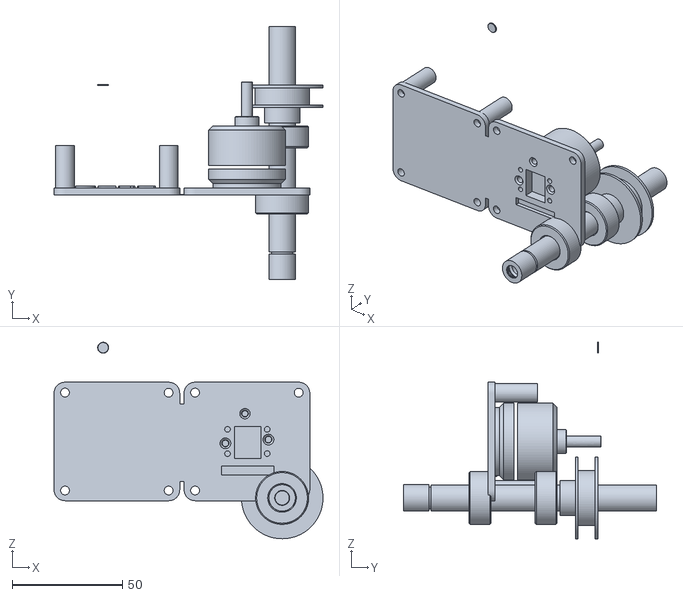
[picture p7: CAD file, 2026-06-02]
hardware/Kicad/Main_PCB/Solventech_Controller/BLDC_TEST_JIG.stl
122.0 x 114.7 x 89.2

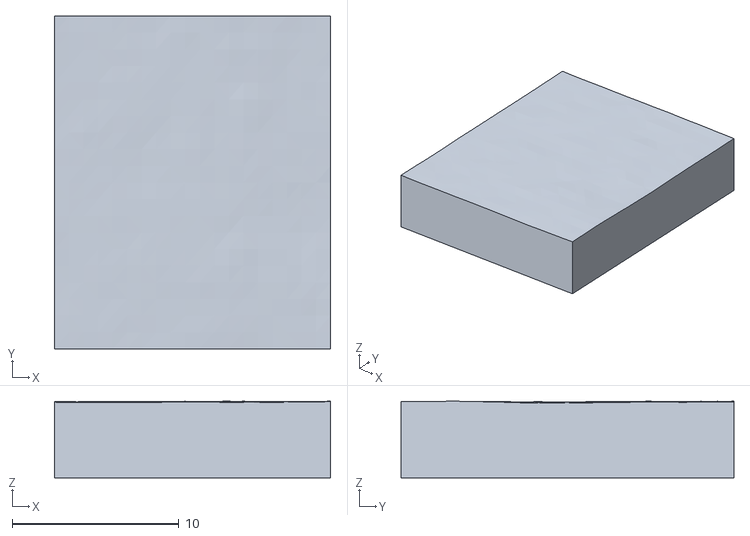
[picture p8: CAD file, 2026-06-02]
hardware/Kicad/Main_PCB/Solventech_Controller/terrain-214050/terrain-214050.stl
16.6 x 20.0 x 4.61

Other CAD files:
hardware/Kicad/Main_PCB/Solventech_Controller/pressure-sensor-hx710b-1.snapshot.3/pressure_sensor_assy_HX710B.IGS

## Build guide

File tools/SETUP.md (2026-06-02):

# VerveFlo — Setup & Flashing Guide

This guide explains everything needed to flash and run the main VerveFlo
firmware (`verveflo.ino`) on the device. No prior firmware experience needed —
just follow the steps in order.

---

## 1. What you need

**Hardware**
- The assembled VerveFlo board (ESP32-S3)
- A USB-C cable (data cable, not charge-only)
- A Windows / Mac / Linux computer
- A phone or laptop with WiFi (for first-time setup)

**Software**
- Arduino IDE 2.x — download free from https://www.arduino.cc/en/software

---

## 2. One-time computer setup

### 2.1 Add the ESP32 board support
1. Open Arduino IDE
2. Go to **File → Preferences**
3. In **Additional Boards Manager URLs**, paste:
   ```
   https://espressif.github.io/arduino-esp32/package_esp32_index.json
   ```
4. Click OK
5. Go to **Tools → Board → Boards Manager**, search **esp32**, install
   **"esp32 by Espressif Systems"**

### 2.2 Install the required libraries
Go to **Tools → Manage Libraries** and install:
| Library | Search for | By |
|---|---|-----|
| U8g2 | `U8g2` | olikraus | 
| Q2HX711 | `Queuetue HX711` | bogde / Queuetue | https://github.com/queuetue/Q2-HX711-Arduino-Library | 

(WiFi, WebServer, DNSServer, Preferences come built in with the ESP32 core — nothing to install.)

---

## 3. Board settings (important)

Open `verveflo.ino`, then under **Tools** set exactly:

| Setting | Value |
|---|---|
| Board | **ESP32S3 Dev Module** |
| USB CDC On Boot | **Enabled**  ← critical, else serial won't work |
| Partition Scheme | Default 4MB with spiffs |
| Upload Speed | 921600 |

Then under **Tools → Port**, select the port that appears when you plug in
the board (e.g. `COM5` on Windows, `/dev/ttyACM0` on Linux).

---

## 4. Flash the firmware

1. Open `verveflo/verveflo.ino` in Arduino IDE
2. Confirm board settings (Section 3)
3. Click the **→ Upload** button (arrow, top-left)
4. Wait for **"Done uploading"** at the bottom

> If upload fails: hold the **BOOT** button on the board, press **RESET** once,
> release BOOT, then click Upload again.

---

## 5. First-time WiFi setup

The device hosts its own setup page on first power-up.

1. Power on the device
2. On your phone, open WiFi settings — connect to the hotspot named
   **`VerveFlo-Setup`**
3. A setup page should open automatically. If not, open a browser and go to:
   ```
   192.168.4.1
   ```
4. Pick your home/clinic WiFi from the list, enter the password, tap **Save**
5. The device restarts and connects to your WiFi
6. Its new IP address is shown on the **OLED screen** and in the Serial Monitor

To reset WiFi later: serial command `wificlear`, or hold the reset
sequence — device returns to `VerveFlo-Setup` hotspot mode.

---

## 6. Open the control app

On any phone or laptop **on the same WiFi**, open a browser and go to:
```
http://[device-IP]
```
(the IP shown on the OLED, e.g. `http://192.168.1.42`)

The web app lets you start/stop sessions, set pressure level, set time,
and choose mode. No app install — it runs in the browser.

---

## 7. Verify hardware (recommended once)

Open **Serial Monitor** (magnifier icon, top-right). Set:
- Baud: **115200**
- Line ending: **Newline**

Then type:
| Command | What it does |
|---|---|
| `help` | Full command list |
| `zero` | Set pressure zero — do this with cuffs open to air |
| `selftest` | Auto-checks LED, battery, pressure, pump, all valves |
| `status` | Current device state |

If `selftest` reports all components OK and the web app loads, the device
is ready to use.

---

## 8. Package contents

| File / folder | What it is |
|---|---|
| `verveflo/verveflo.ino` | Main firmware — the one you flash |
| `tools/` | Diagnostic sketches (only needed for troubleshooting) |
| `hardware/pin_map.md` | Pin assignments reference |
| `docs/` | Setup, calibration, troubleshooting docs |
| `README.md` | Overview |

---

## 9. Quick troubleshooting

| Symptom | Check |
|---|---|
| Nothing on Serial Monitor | USB CDC On Boot = Enabled, baud = 115200 |
| Upload fails | Hold BOOT + tap RESET, retry |
| Web page won't load | Device + phone on same WiFi? Use IP from OLED |
| Pressure reads wrong | Run `zero` with cuffs open to atmosphere |
| Pump runs, no inflation | Check cuff tubing + release valve seated |
| Can't find `VerveFlo-Setup` | Send `wificlear` over serial to reset WiFi |

For deeper hardware faults, flash the sketches in `tools/` — see their
header comments for command lists.

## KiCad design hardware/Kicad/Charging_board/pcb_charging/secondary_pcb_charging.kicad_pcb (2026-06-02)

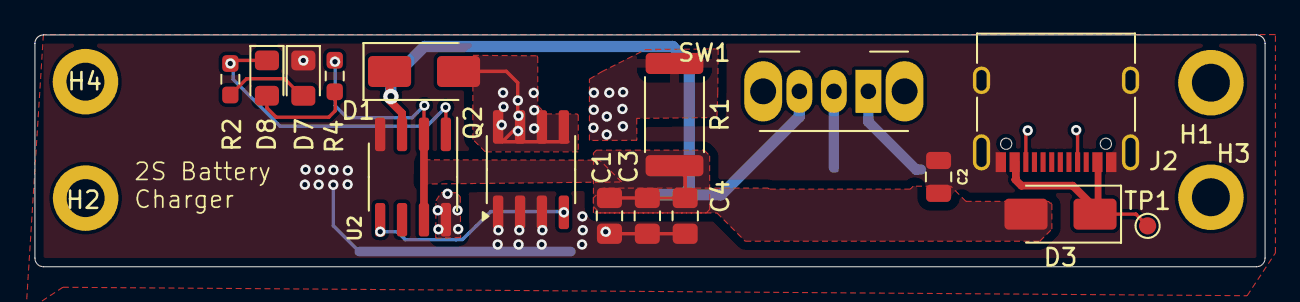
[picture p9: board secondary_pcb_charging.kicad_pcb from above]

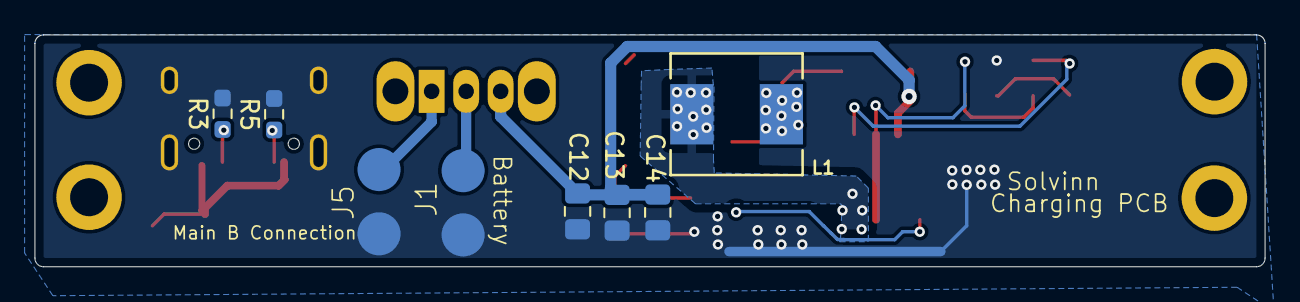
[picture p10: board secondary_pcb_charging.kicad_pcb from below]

Board: 2 copper layers, 71.3 x 13.4 mm, 28 parts (8 on the bottom side), 14 nets.

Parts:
C1, C3, C4, C12, C13, C14: 100nf; C_0805_2012Metric_Pad1.18x1.45mm_HandSolder
C2: 1uF_0805; C_0805_2012Metric
D1: SS34; D_SMA
D3: SS14; D_SMA
D7: RED LED; LED_0805_2012Metric_Pad1.15x1.40mm_HandSolder
D8: GREEN LED; LED_0805_2012Metric_Pad1.15x1.40mm_HandSolder
H1, H2, H3, H4: MountingHole; MountingHole_2.2mm_M2_DIN965_Pad
J1, J5: JST-S2B-XH_Sideentry; Solder_pad2
J2: USB_C_Receptacle_USB2.0_16P; USB_C_Receptacle_XKB_U262-16XN-4BVC11
L1: 10uh; LMLP07A7M1R0DTAS_AVX
Q2: IRF7832; SOIC-8_3.9x4.9mm_P1.27mm
R1: 50mohm_2512; R_2512
R2, R4: 2.2k; R_0603_1608Metric_Pad0.98x0.95mm_HandSolder
R3, R5: 5.1K; R_0603_1608Metric_Pad0.98x0.95mm_HandSolder
SW1: SW_Slide_SPDT_Straight_CK_OS102011MS2Q; SW_Slide_SPDT_Angled_CK_OS102011MA1Q
TP1: TestPoint; TestPoint_Pad_D1.0mm
U2: CN3302; SOIC-8_3.9x4.9mm_P1.27mm

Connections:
/8.4: J5.2, SW1.1 (C)
/ Battery_out: J1.2, SW1.2 (B)
/VBAT: C12.2, C13.2, C14.2, D1.1 (K), SW1.3 (A), U2.3 (BAT)
/cc1: J2.A5 (CC1), R3.1
/cc2: J2.B5 (CC2), R5.1
GND: C1.2, C2.1, C2.2, C3.2, C4.2, C12.1, C13.1, C14.1, D7.1 (K), J1.1, J2.A1 (GND), J2.A12 (GND), J2.B1 (GND), J2.B12 (GND), J2.S1 (SHIELD), J5.1, Q2.1 (S), Q2.2 (S), Q2.3 (S), R3.2, R5.2, U2.4 (GND)
unnamed: D1.2 (A), L1.2, Q2.5 (D), Q2.6 (D), Q2.7 (D), Q2.8 (D)
unnamed: D3.1 (K), J2.A4 (VBUS), J2.A9 (VBUS), J2.B4 (VBUS), J2.B9 (VBUS), TP1.1
unnamed: D7.2 (A), R2.1
unnamed: D8.2 (A), R4.1
unnamed: D8.1 (K), R2.2, U2.1 (STAT)
unnamed: Q2.4 (G), U2.5 (LDRV)
unnamed: L1.1, R1.1, U2.8 (CSN)
VBUS: C1.1, C3.1, C4.1, D3.2 (A), R1.2, R4.2, U2.2 (CE), U2.7 (VIN)

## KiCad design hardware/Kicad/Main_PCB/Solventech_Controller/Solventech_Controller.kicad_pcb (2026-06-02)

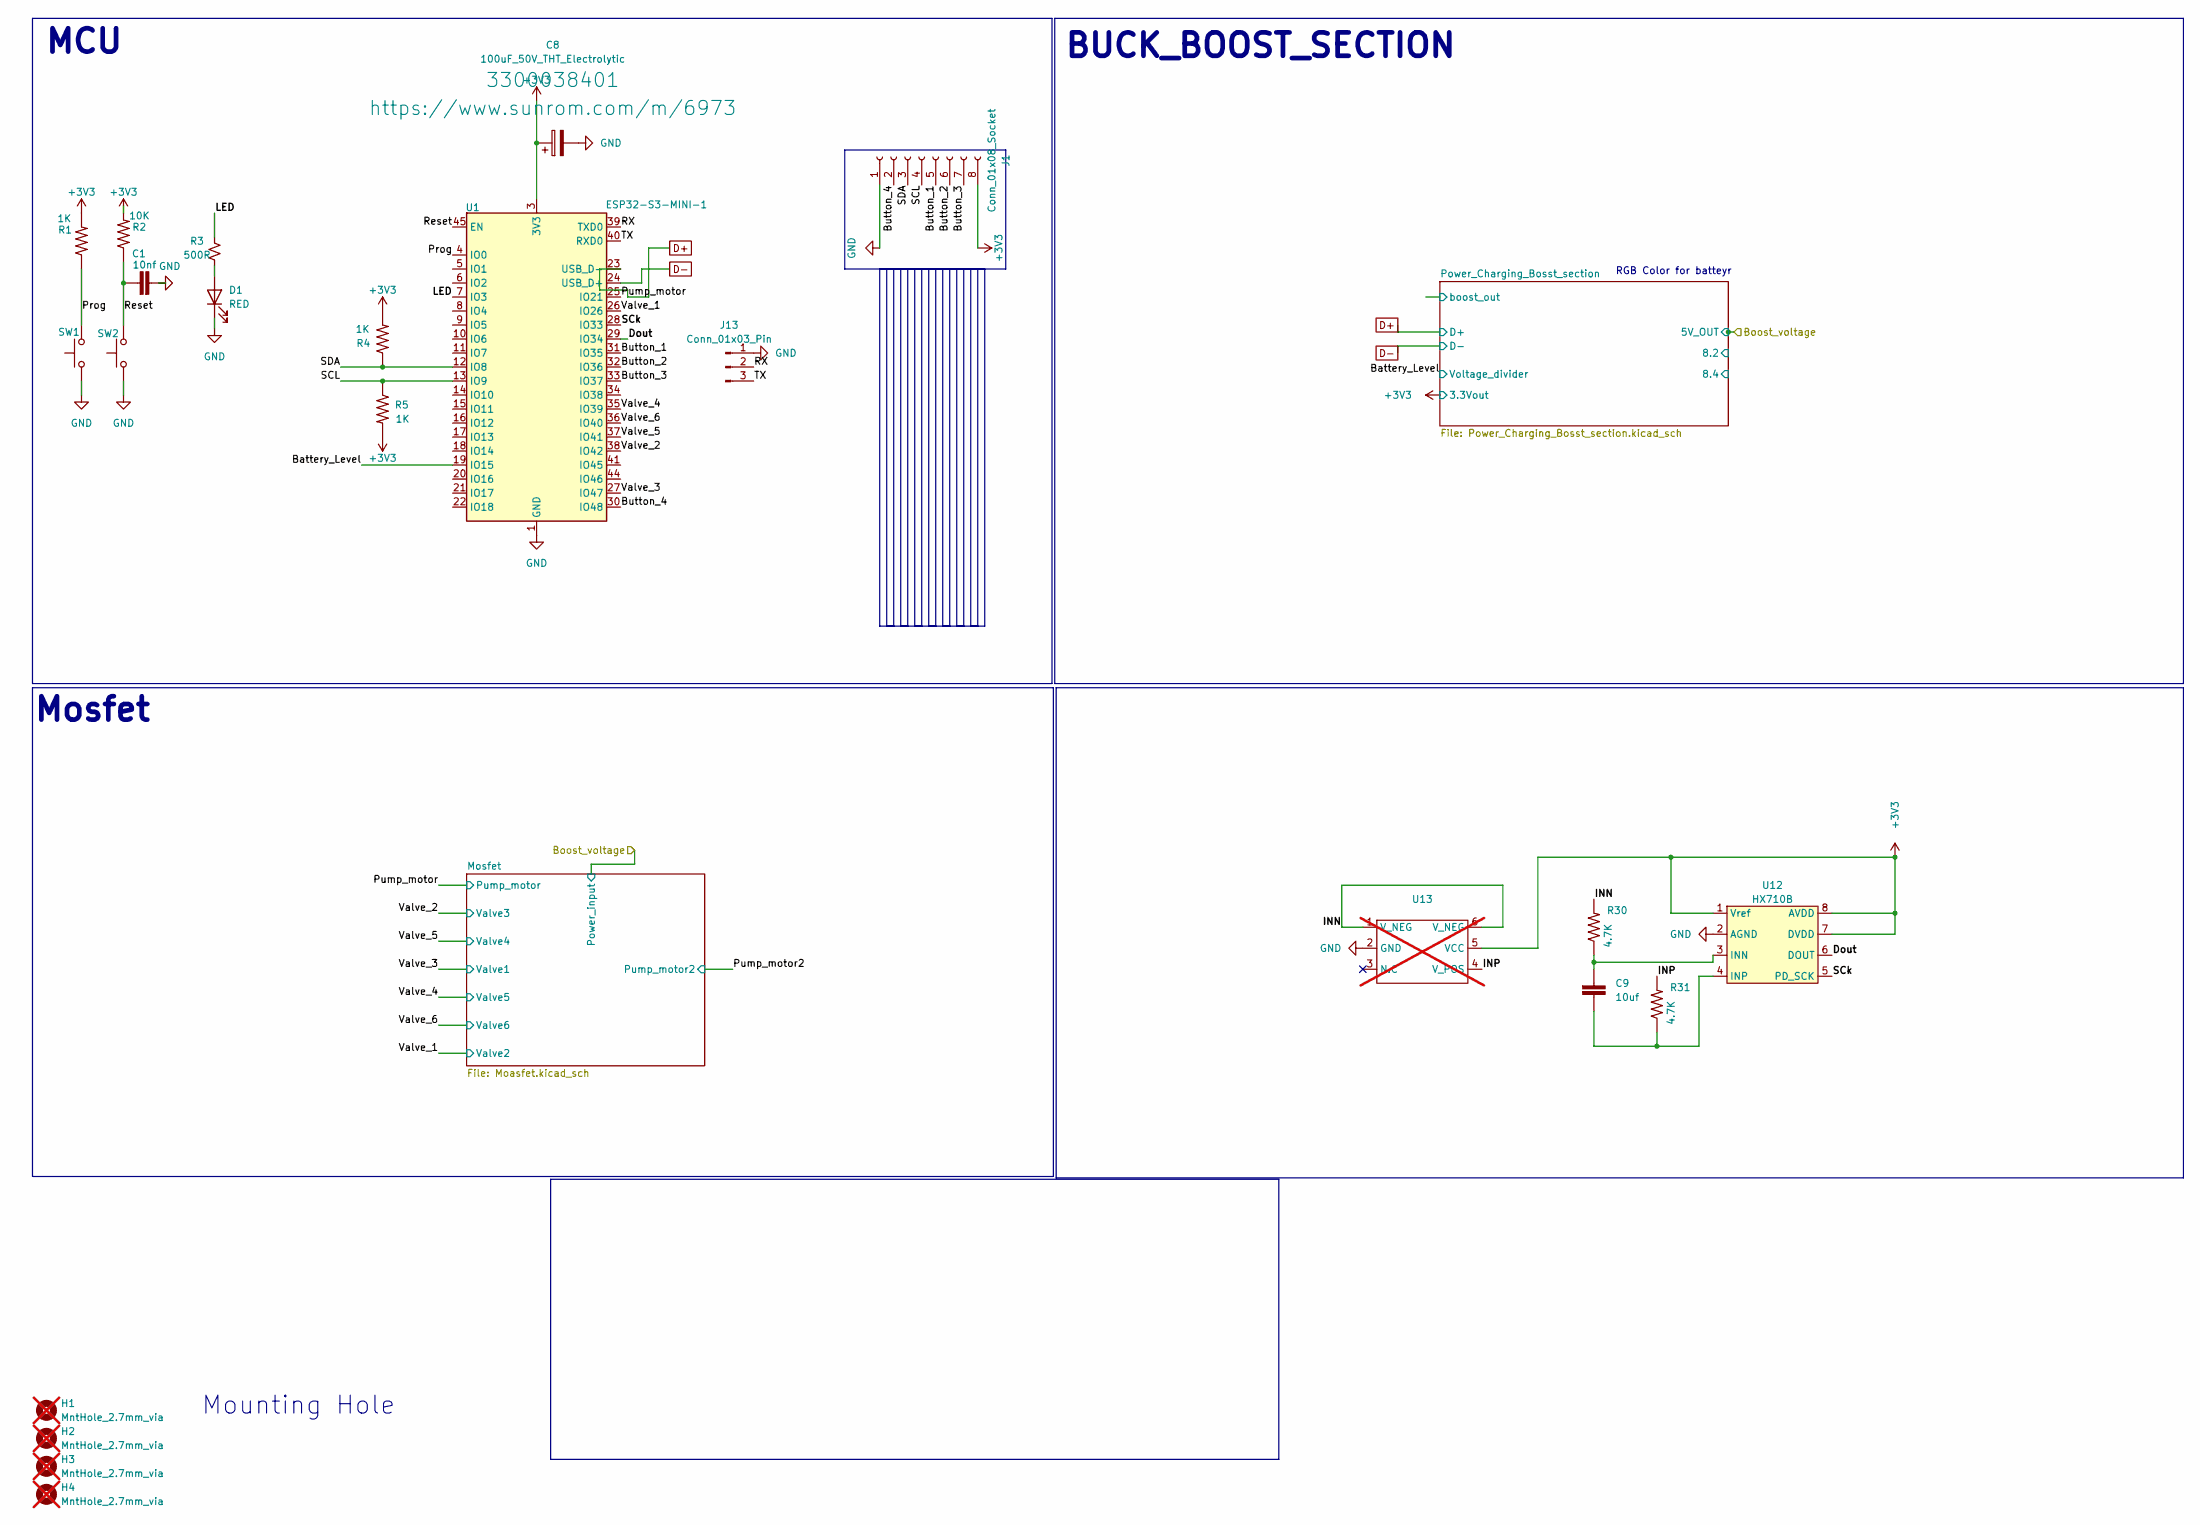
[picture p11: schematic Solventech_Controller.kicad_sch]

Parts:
C1: 10nf; Cap_0603_1608Metric
C8: 100uF_50V_THT_Electrolytic; CP_Elec_5x3; Morphle Part no. 3300038401
C9: 10uf; Cap_0603_1608Metric
D1: RED; LED_0603_1608Metric; LCSC C71911
H1, H2, H3, H4: MntHole_2.7mm_via; MountingHole_2.2mm_M2_DIN965; not fitted
J1: Conn_01x08_Socket; FFC_Connector_8pos
J13: Conn_01x03_Pin; JST_XH_B3B-XH-AM_1x03_P2.50mm_Vertical; MPN B3B-XH-AM_1x03
R1, R4, R5: 1K; R_0603_1608Metric
R2: 10K; R_0603_1608Metric
R3: 500R; R_0603_1608Metric; LCSC C25905
R30, R31: 4.7K; R_0603_1608Metric
SW1, SW2: SW_Push; SKRPABE010; MPN SKRPABE010; LCSC C720477
U1: ESP32-S3-MINI-1; ESP32-S2-MINI-1; MPN ESP32-S3-MINI-1
U12: HX710B; SOIC-8_3.9x4.9mm_P1.27mm; MPN HX710B
U13: Untitled; not fitted

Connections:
+3V3: C8.1, J1.8, R1.2, R2.2, R4.2, R5.2, U1.3 (3V3), U12.1 (Vref), U12.7 (DVDD), U12.8 (AVDD), U13.5 (VCC); also elsewhere on the board
/Battery_Level: U1.19 (IO15); also elsewhere on the board
/Button_1: J1.5, U1.31 (IO35)
/Button_2: J1.6, U1.32 (IO36)
/Button_3: J1.7, U1.33 (IO37)
/Button_4: J1.2, U1.30 (IO48)
/Dout: U1.29 (IO34), U12.6 (DOUT)
/INN: R30.2, U13.1 (V_NEG), U13.6 (V_NEG)
/INP: R31.2, U13.4 (V_POS)
/LED: R3.2, U1.7 (IO3)
/Prog: R1.1, SW1.2, U1.4 (IO0)
/Pump_motor: U1.25 (IO21); also elsewhere on the board
/RX: J13.2, U1.39 (TXD0)
/Reset: C1.1, R2.1, SW2.2, U1.45 (EN)
/SCL: J1.4, R5.1, U1.13 (IO9)
/SCk: U1.28 (IO33), U12.5 (PD_SCK)
/SDA: J1.3, R4.1, U1.12 (IO8)
/TX: J13.3, U1.40 (RXD0)
/Valve_1: U1.26 (IO26); also elsewhere on the board
/Valve_2: U1.38 (IO42); also elsewhere on the board
/Valve_3: U1.27 (IO47); also elsewhere on the board
/Valve_4: U1.35 (IO39); also elsewhere on the board
/Valve_5: U1.37 (IO41); also elsewhere on the board
/Valve_6: U1.36 (IO40); also elsewhere on the board
D+: U1.23 (USB_D-); also elsewhere on the board
D-: U1.24 (USB_D+); also elsewhere on the board
GND: C1.2, C8.2, D1.1 (K), J1.1, J13.1, SW1.1, SW2.1, U1.1 (GND), U1.2 (GND), U1.42 (GND), U1.43 (GND), U1.46 (GND), U1.47 (GND), U1.48 (GND), U1.49 (GND), U1.50 (GND), U1.51 (GND), U1.52 (GND), U1.53 (GND), U1.54 (GND), U1.55 (GND), U1.56 (GND), U1.57 (GND), U1.58 (GND), U1.59 (GND), U1.60 (GND), U1.61 (GND), U1.62 (GND), U1.63 (GND), U1.64 (GND), U1.65 (GND), U12.2 (AGND), U13.2 (GND); also elsewhere on the board
unnamed: D1.2 (A), R3.1
unnamed: C9.1, R30.1, U12.3 (INN)
unnamed: C9.2, R31.1, U12.4 (INP)

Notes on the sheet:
Mosfet
MCU
RGB Color for batteyr
BUCK_BOOST_SECTION
Mounting Hole

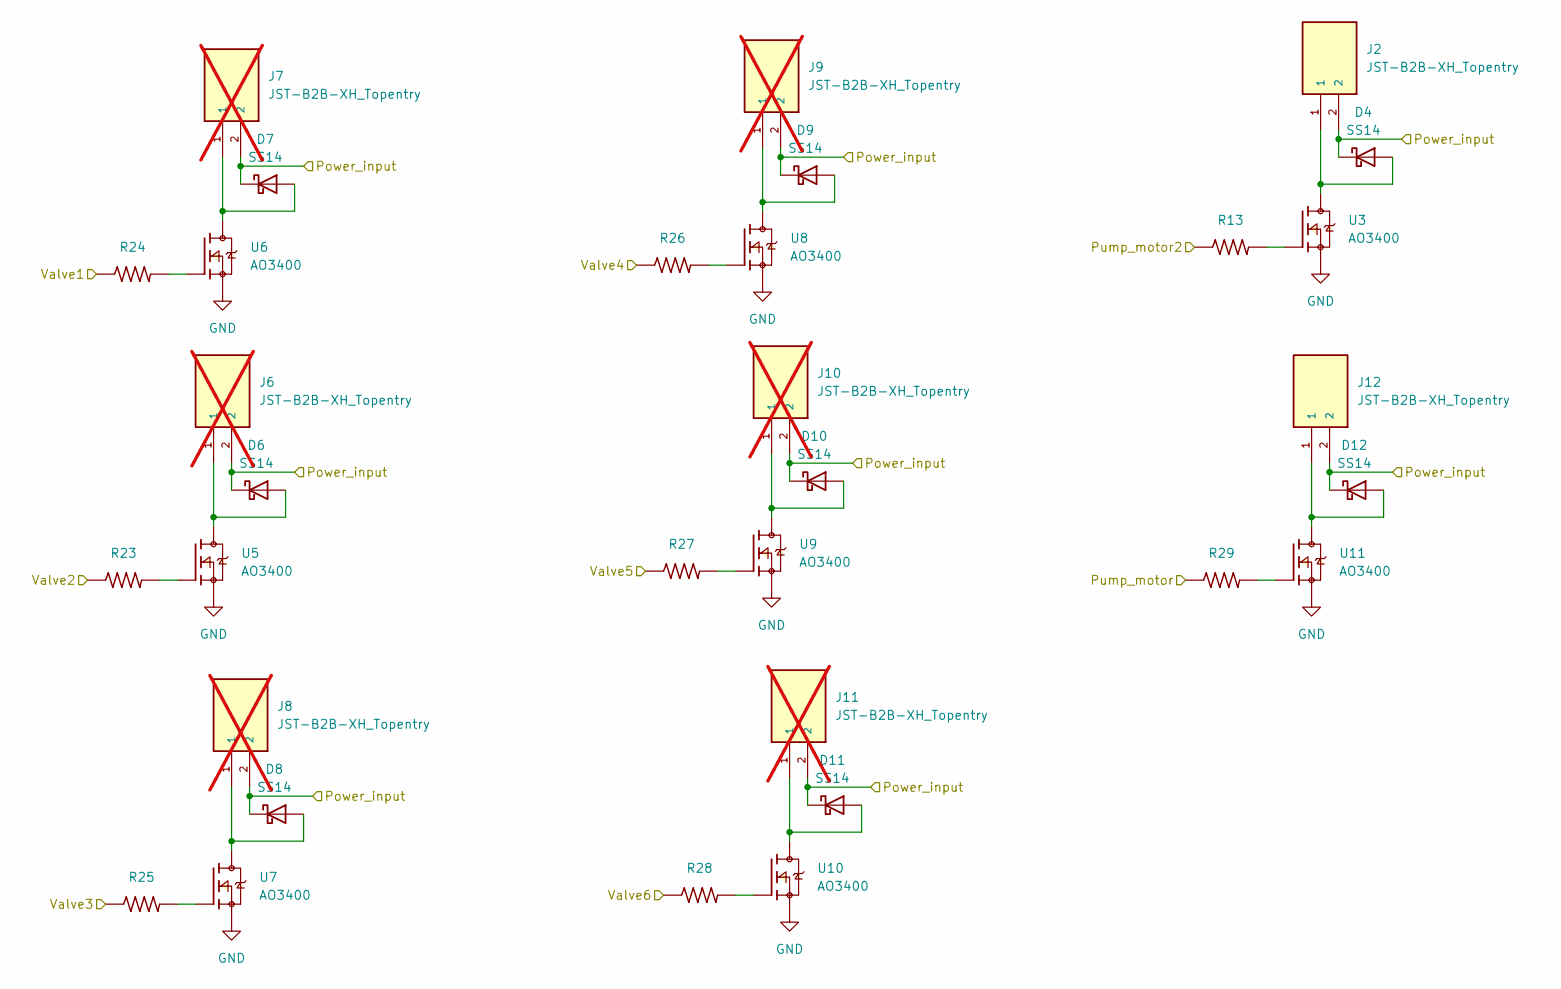
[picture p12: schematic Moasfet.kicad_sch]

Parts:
D4, D6, D7, D8, D9, D10, D11, D12: SS14; D_SMA; MPN SS14
J2, J12: JST-B2B-XH_Topentry; JST_PH_S2B-PH-SM4-TB_1x02-1MP_P2.00mm_Horizontal; Morphle Part no. 3300043701
J6, J7, J8, J9, J10, J11: JST-B2B-XH_Topentry; Solder_pad2; Morphle Part no. 3300043701; not fitted
R13, R23, R24, R25, R26, R27, R28, R29: 33R; R_0603_1608Metric
U3, U5, U6, U7, U8, U9, U10, U11: AO3400; SOT-23; MPN AO3400

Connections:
/Boost_voltage: D4.1 (K), D6.1 (K), D7.1 (K), D8.1 (K), D9.1 (K), D10.1 (K), D11.1 (K), D12.1 (K), J2.2, J6.2, J7.2, J8.2, J9.2, J10.2, J11.2, J12.2; also elsewhere on the board
/Pump_motor: R29.1; also elsewhere on the board
/Pump_motor2: R13.1
/Valve_1: R23.1; also elsewhere on the board
/Valve_2: R25.1; also elsewhere on the board
/Valve_3: R24.1; also elsewhere on the board
/Valve_4: R27.1; also elsewhere on the board
/Valve_5: R26.1; also elsewhere on the board
/Valve_6: R28.1; also elsewhere on the board
GND: U3.2, U5.2, U6.2, U7.2, U8.2, U9.2, U10.2, U11.2; also elsewhere on the board
unnamed: D4.2 (A), J2.1, U3.3
unnamed: D6.2 (A), J6.1, U5.3
unnamed: D7.2 (A), J7.1, U6.3
unnamed: D8.2 (A), J8.1, U7.3
unnamed: D9.2 (A), J9.1, U8.3
unnamed: D10.2 (A), J10.1, U9.3
unnamed: D11.2 (A), J11.1, U10.3
unnamed: D12.2 (A), J12.1, U11.3
unnamed: R13.2, U3.1
unnamed: R23.2, U5.1
unnamed: R24.2, U6.1
unnamed: R25.2, U7.1
unnamed: R26.2, U8.1
unnamed: R27.2, U9.1
unnamed: R28.2, U10.1
unnamed: R29.2, U11.1

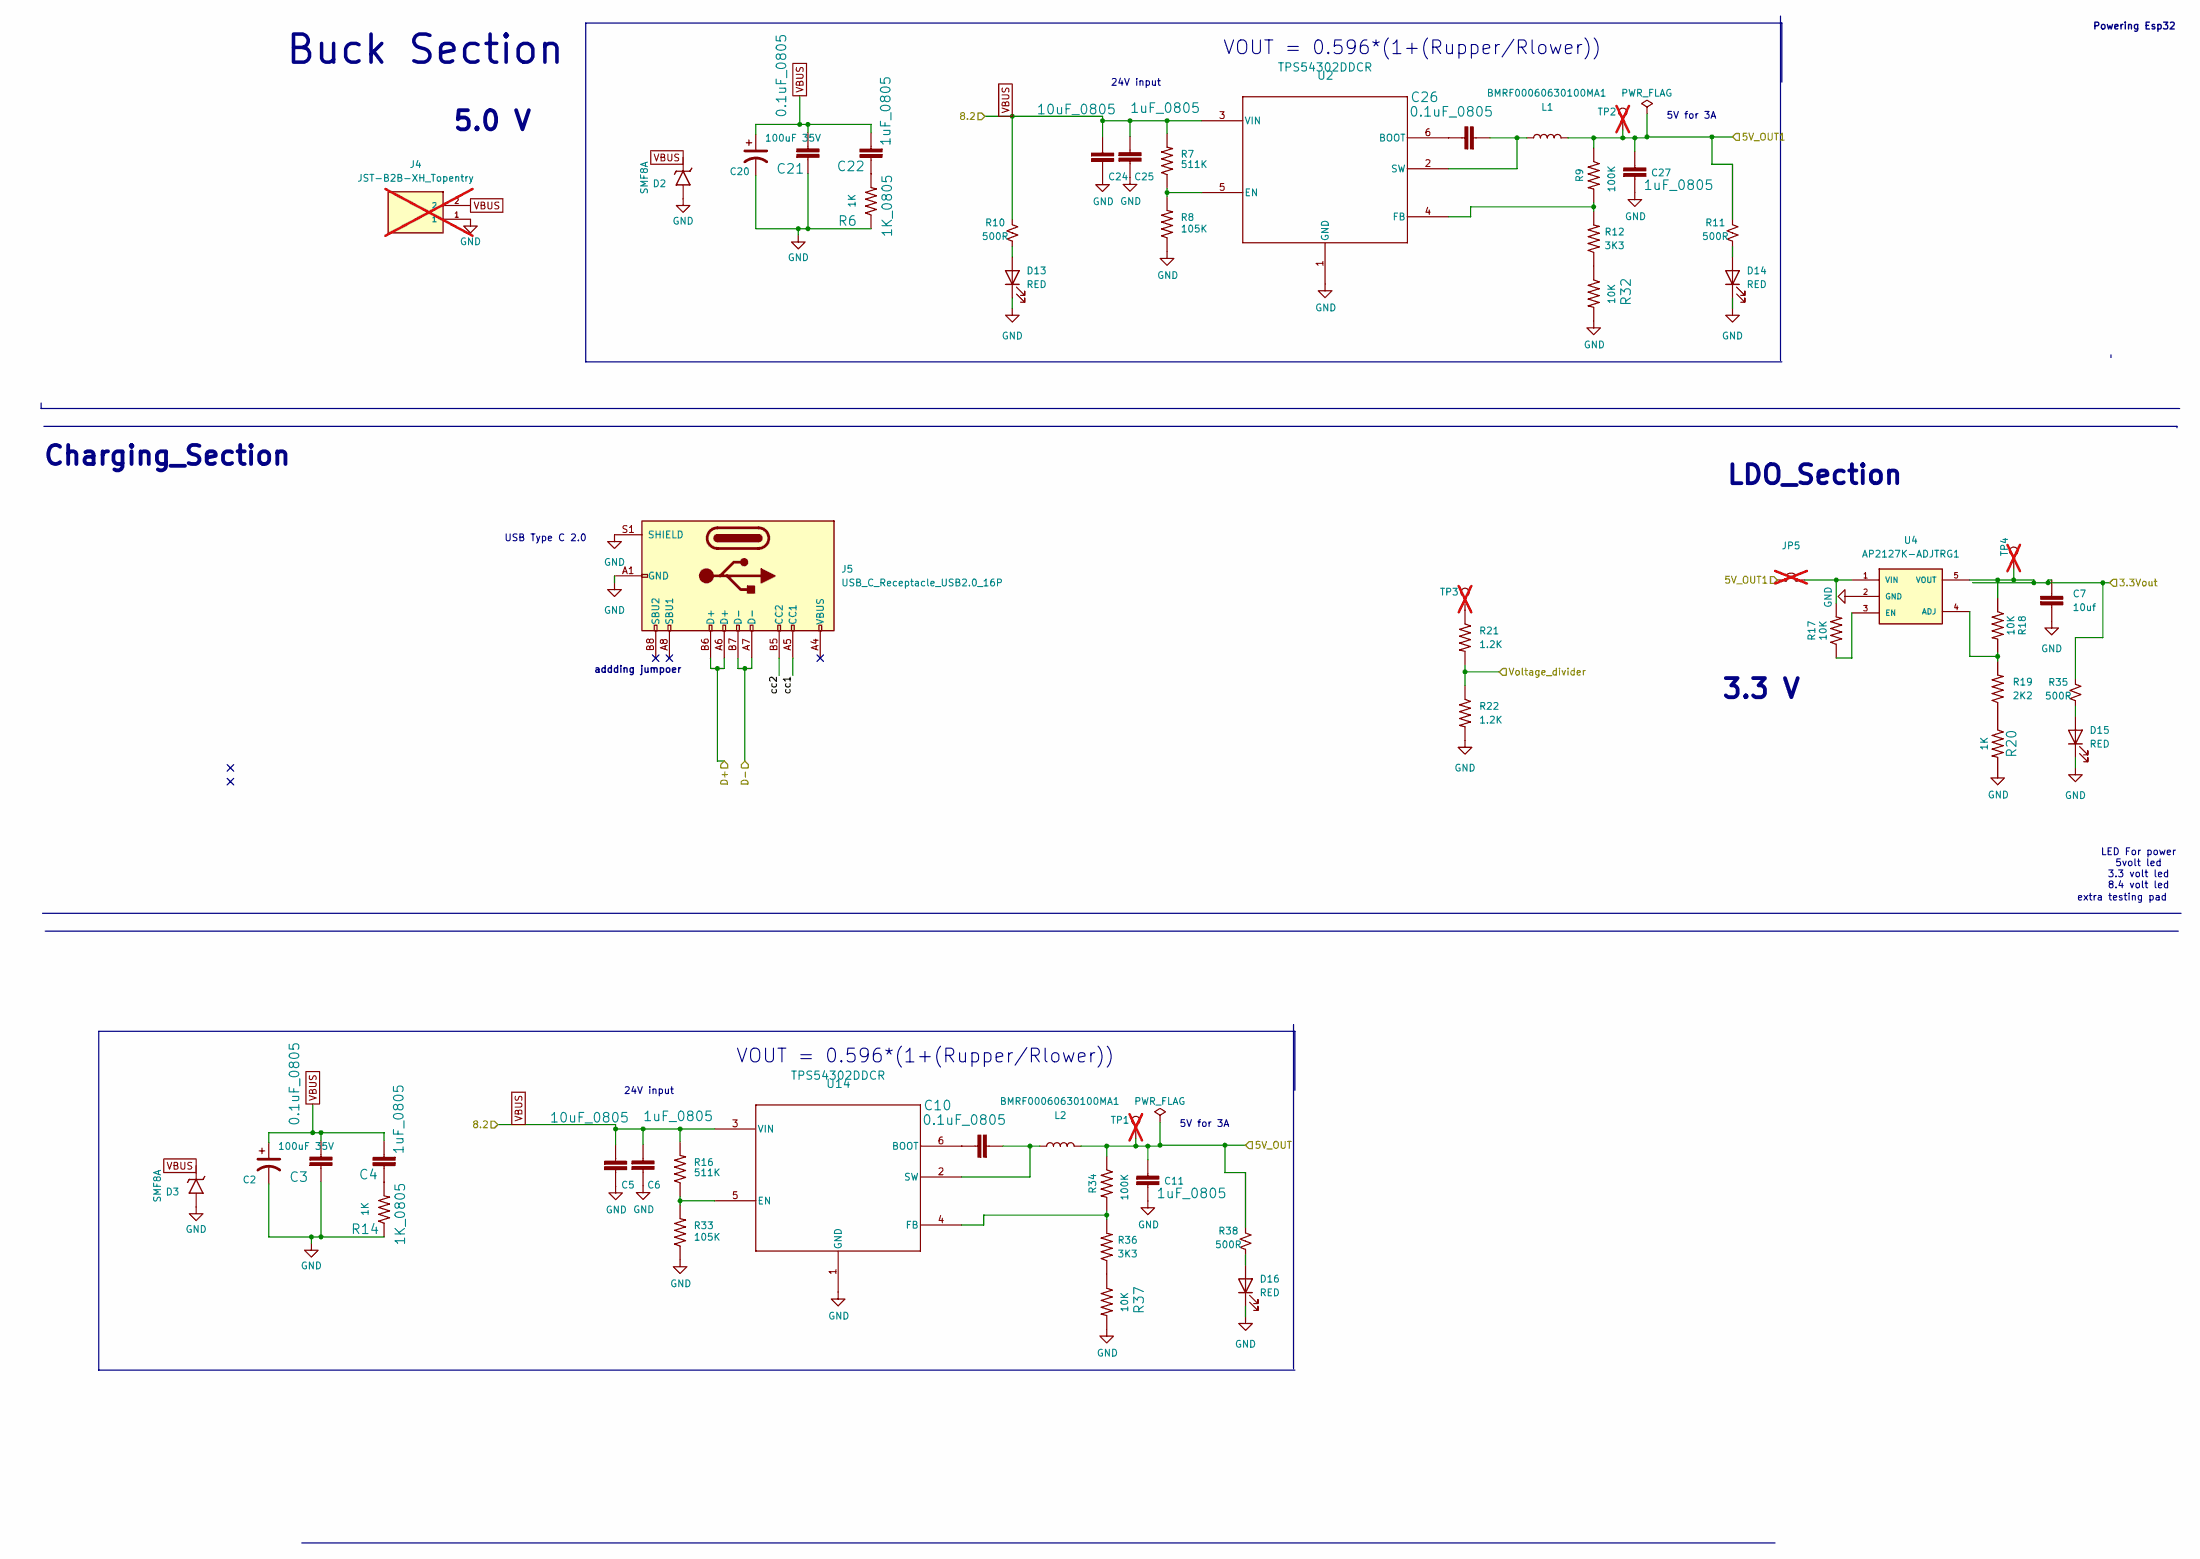
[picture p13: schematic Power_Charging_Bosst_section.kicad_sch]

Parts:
C2, C20: 100uF-35V; CP_EIA-2012-15_AVX-P; Morphle Part no. 3300036001
C3, C10, C21, C26: 0.1uF_0805; C_0805_2012Metric; Morphle Part no. 3300039201
C4, C6, C11, C22, C25, C27: 1uF_0805; C_0805_2012Metric; Morphle Part no. 3300039201
C5, C24: 10uF_0805; C_0805_2012Metric; Morphle Part no. 3300039201
C7: 10uf; Cap_0603_1608Metric
D2, D3: SMF8A; SOD123F; MPN SMF8A; Digi-Key Part Number F5824CT-ND
D13, D14, D15, D16: RED; LED_0603_1608Metric; LCSC C71911
J4: JST-B2B-XH_Topentry; Solder_pad2; Morphle Part no. 3300043701; not fitted
J5: USB_C_Receptacle_USB2.0_16P; USB_C_Receptacle_XKB_U262-16XN-4BVC11; MPN Receptacle_XKB_U262-16XN-4BVC11
JP5: Jumper_2_Small_Open; SolderJumper-2_P1.3mm_Open_RoundedPad1.0x1.5mm; not fitted
L1, L2: BMRF00060630100MA1; LMLP07A7M1R0DTAS_AVX; MPN BMRF00060630100MA1; Digi-Key Part Number 553-BMRF00060630100MA1CT-ND
R6, R14: 1K_0805; R_0805_2012Metric; Morphle Part no. 3300044701
R7, R16: 511K_0603; R_0603_1608Metric
R8, R33: 105K_0603; R_0603_1608Metric
R9, R34: 100K_0603; R_0603_1608Metric; Morphle Part no. 3300039401
R10, R11, R35, R38: 500R; R_0603_1608Metric; LCSC C25905
R12, R36: 3K3_0603; R_0603_1608Metric; Morphle Part no. 3300044501
R17, R18, R32, R37: 10K_0603; R_0603_1608Metric; Morphle Part no. 3300039401
R19: 2K2_0603; R_0603_1608Metric; Morphle Part no. 3300044501
R20: 1K_0603; R_0603_1608Metric; Morphle Part no. 3300039301
R21, R22: 1.2K; R_0603_1608Metric
TP1, TP2, TP3, TP4: TestPoint; TestPoint_Pad_D1.0mm; not fitted
U2, U14: TPS54302DDCR; SOT-23-6; MPN TPS54302DDCR; Digi-Key Part Number 296-46237-1-ND
U4: AP2127K-ADJTRG1; SOT-23-5; MPN AP2127K-ADJTRG1; Digi-Key Part Number AP2127K-ADJTRG1DICT-ND

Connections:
+3V3: C7.1, R18.1, R35.2, TP4.1, U4.5 (VOUT); also elsewhere on the board
/Battery_Level: R21.2, R22.1; also elsewhere on the board
/Boost_voltage: C11.1, L2.2, R34.1, R38.2, TP1.1; also elsewhere on the board
/Power_Charging_Bosst_section/5V_OUT1: C27.1, JP5.1 (A), L1.2, R9.1, R11.2, TP2.1
/Power_Charging_Bosst_section/cc1: J5.A5 (CC1)
/Power_Charging_Bosst_section/cc2: J5.B5 (CC2)
D+: J5.A6 (D+), J5.B6 (D+); also elsewhere on the board
D-: J5.A7 (D-), J5.B7 (D-); also elsewhere on the board
GND: C2.2, C3.2, C5.2, C6.2, C7.2, C11.2, C20.2, C21.2, C24.2, C25.2, C27.2, D2.2 (A), D3.2 (A), D13.1 (K), D14.1 (K), D15.1 (K), D16.1 (K), J4.1, J5.A1 (GND), J5.A12 (GND), J5.B1 (GND), J5.B12 (GND), J5.S1 (SHIELD), R6.1, R8.1, R14.1, R20.2, R22.2, R32.2, R33.1, R37.2, U2.1 (GND), U4.2 (GND), U14.1 (GND); also elsewhere on the board
unnamed: C4.1, R14.2
unnamed: C22.1, R6.2
unnamed: D13.2 (A), R10.1
unnamed: D14.2 (A), R11.1
unnamed: D15.2 (A), R35.1
unnamed: D16.2 (A), R38.1
unnamed: JP5.2 (B), R17.2, U4.1 (VIN)
unnamed: R12.1, R32.1
unnamed: R19.1, R20.1
unnamed: R21.1, TP3.1
unnamed: R36.1, R37.1
unnamed: C26.1, U2.6 (BOOT)
unnamed: R7.1, R8.2, U2.5 (EN)
unnamed: R9.2, R12.2, U2.4 (FB)
unnamed: C26.2, L1.1, U2.2 (SW)
unnamed: R18.2, R19.2, U4.4 (ADJ)
unnamed: R17.1, U4.3 (EN)
unnamed: C10.1, U14.6 (BOOT)
unnamed: R16.1, R33.2, U14.5 (EN)
unnamed: R34.2, R36.2, U14.4 (FB)
unnamed: C10.2, L2.1, U14.2 (SW)
VBUS: C2.1, C3.1, C4.2, C5.1, C6.1, C20.1, C21.1, C22.2, C24.1, C25.1, D2.1 (C), D3.1 (C), J4.2, R7.2, R10.2, R16.2, U2.3 (VIN), U14.3 (VIN)

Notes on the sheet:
24V input
5V for 3A
addding jumpoer
Powering Esp32
extra testing pad
LDO_Section
VOUT = 0.596*(1+(Rupper/Rlower))
5.0 V
Buck Section
USB Type C 2.0
LED For power 5volt led 3.3 volt led 8.4 volt led
Charging_Section
3.3 V

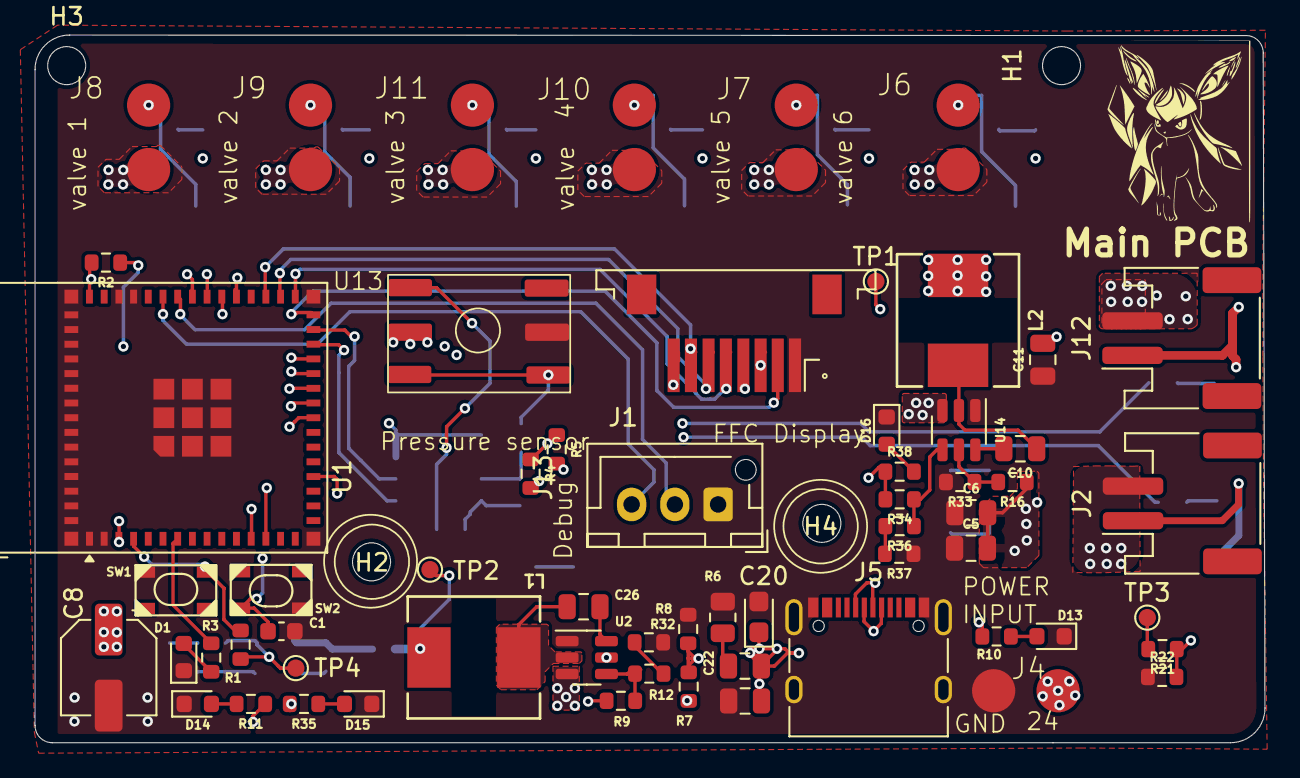
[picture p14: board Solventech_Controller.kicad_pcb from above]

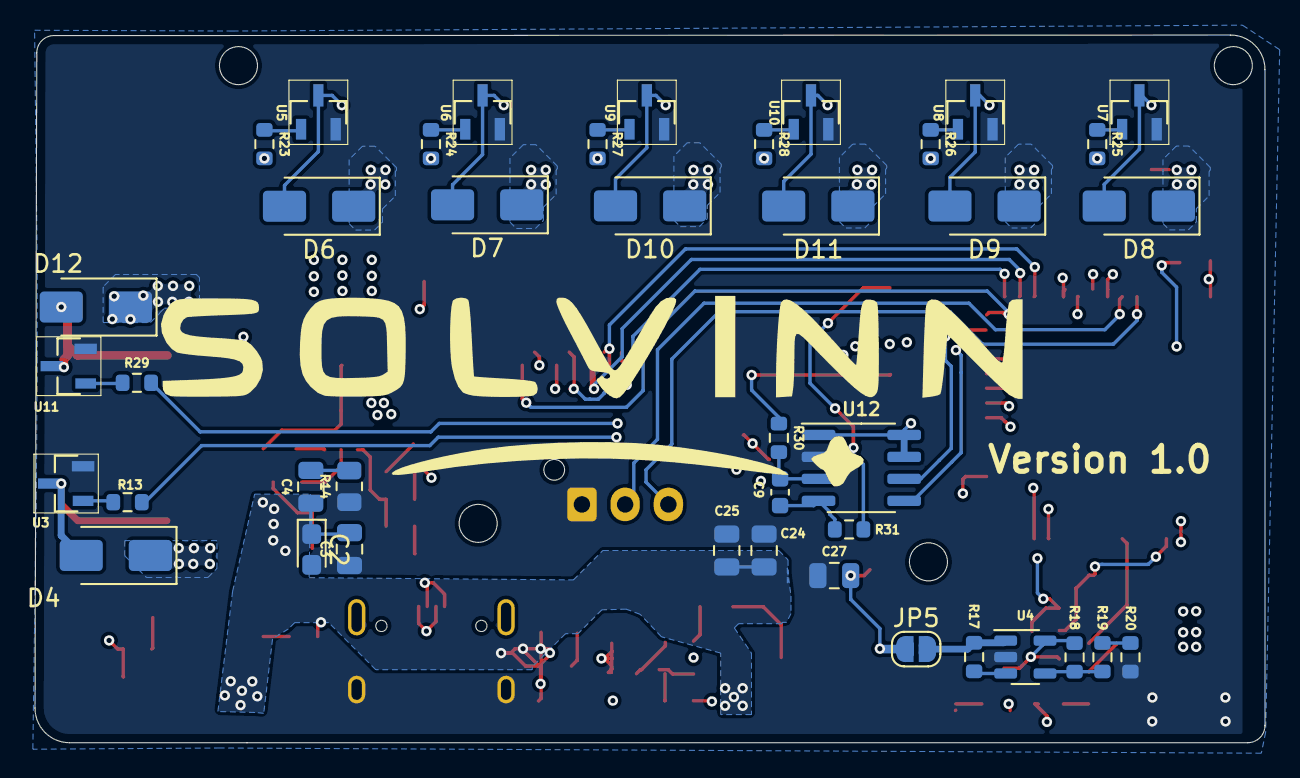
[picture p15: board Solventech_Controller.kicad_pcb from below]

Board: 4 copper layers, 71.1 x 40.9 mm, 106 parts (41 on the bottom side), 70 nets.

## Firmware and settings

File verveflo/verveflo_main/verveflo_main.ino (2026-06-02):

/*
 * ╔══════════════════════════════════════════════════════════╗
 * ║              VerveFlo  v3.1  —  Complete Firmware        ║
 * ║         ESP32-S3 · Arduino IDE · All-in-One              ║
 * ╠══════════════════════════════════════════════════════════╣
 * ║  FIXES v3.1:                                             ║
 * ║  • Release valve (VR) logic inverted (normally-open)     ║
 * ║  • CALIB_M positive (raw increases with pressure)        ║
 * ║  • CALIB_ZERO offset in readPressure()                   ║
 * ║  • HX710B overflow filter (raw > 16000000)               ║
 * ║  • Motor soft start via analogWrite (no ledcWrite)       ║
 * ║  • 'zero' serial command for live calibration            ║
 * ╚══════════════════════════════════════════════════════════╝
 *
 * LIBRARIES (Tools → Manage Libraries):
 *   U8g2              by olikraus
 *   Q2HX711           by bogde (search Queuetue)
 *   WiFi/WebServer/DNSServer/Preferences → built into ESP32 core
 *
 * BOARD SETTINGS:
 *   Board             : ESP32S3 Dev Module
 *   USB CDC On Boot   : Enabled  ← MUST or serial won't work
 *   Partition Scheme  : Default 4MB with spiffs
 *   Upload Speed      : 921600
 *
 * PIN MAP (verified from hardware sheet):
 *   Fill Valve 1  GPIO 26    Release Valve  GPIO 42 (normally-open)
 *   Fill Valve 2  GPIO 47    Pump Motor     GPIO 21
 *   Fill Valve 3  GPIO 39    LED            GPIO 3
 *   Fill Valve 4  GPIO 40    HX710B Dout    GPIO 34
 *   Fill Valve 5  GPIO 41    HX710B SCK     GPIO 33
 *   BTN Start     GPIO 35    Battery ADC    GPIO 15
 *   BTN Mode      GPIO 36
 *   BTN Pressure  GPIO 37
 *   BTN Time      GPIO 48
 *
 * SERIAL COMMANDS (115200 baud, Newline):
 *   help / status / start / pause / stop / release
 *   pressure / battery / valves / buttons / pins / ip
 *   zero      → set pressure zero at atmosphere
 *   v1-v5 on/off/open/close/0-255
 *   vr on/off/open/close
 *   pump on/off / motor 0-255
 *   pstream / ptest / vsweep / selftest / alloff
 *   led on/off/blink/auto
 *   mode 1-4 / pset 0-2 / time 0-2 / hold N / gap N
 *   wificlear / reboot
 */

#include <Arduino.h>
#include <WiFi.h>
#include <WebServer.h>
#include <DNSServer.h>
#include <Preferences.h>
#include <U8g2lib.h>
#include <Wire.h>
#include <Q2HX711.h>

// ═══════════════════════════════════════════════════════════
//  *** CHANGE THESE TO YOUR WIFI CREDENTIALS ***
//  OR leave blank and use captive portal on first boot
// ═══════════════════════════════════════════════════════════
const char* WIFI_SSID = "";
const char* WIFI_PASS = "";

// ═══════════════════════════════════════════════════════════
//  PINS
// ═══════════════════════════════════════════════════════════
const uint8_t VALVE_PINS[6] = { 26, 47, 39, 40, 41, 42 };
//                               V1   V2   V3   V4   V5   VR
// NOTE: VR (index 5, GPIO 42) is NORMALLY-OPEN — logic inverted
#define RELEASE_VALVE_IDX  5
#define NUM_INFLATE_VALVES 5
#define PUMP_PIN    21
#define LED_PIN     3
#define HX_DATA     34
#define HX_CLK      33
#define BATT_PIN    15
#define BTN_START   35
#define BTN_MODE    36
#define BTN_PRESS   37
#define BTN_TIME    48

// Battery divider (100k + 100k = ratio 2.0)
#define BATT_DIVIDER  2.0f
#define BATT_MAX_V    4.2f
#define BATT_MIN_V    3.0f

// ═══════════════════════════════════════════════════════════
//  OBJECTS
// ═══════════════════════════════════════════════════════════
U8G2_SH1106_128X64_NONAME_F_HW_I2C u8g2(U8G2_R0);
Q2HX711 hx711(HX_DATA, HX_CLK);
WebServer server(80);
DNSServer dnsServer;
Preferences prefs;

// ═══════════════════════════════════════════════════════════
//  WIFI STATE
// ═══════════════════════════════════════════════════════════
bool   g_wifiConnected = false;
bool   g_apMode        = false;
String g_savedSSID     = "";
String g_savedPass     = "";
#define AP_SSID  "VerveFlo-Setup"
#define AP_PASS  ""
#define DNS_PORT 53

// ═══════════════════════════════════════════════════════════
//  PRESSURE CALIBRATION
//  IMPORTANT: CALIB_M is POSITIVE — raw increases with pressure
//  Run 'zero' serial command at atmosphere to set CALIB_ZERO
// ═══════════════════════════════════════════════════════════
float CALIB_M    =  0.00000625f;  // positive slope
float CALIB_B    =  0.0f;
long  CALIB_ZERO =  8388000L;     // update via 'zero' serial command
float g_pressure =  0.0f;

// ═══════════════════════════════════════════════════════════
//  SYSTEM STATE
// ═══════════════════════════════════════════════════════════
enum SystemState {
  STATE_BOOT,
  STATE_READY,
  STATE_RUNNING,
  STATE_PAUSED,
  STATE_RELEASING,
  STATE_DEFLATE_WAIT
};
SystemState g_sysState = STATE_BOOT;

// ═══════════════════════════════════════════════════════════
//  SESSION SETTINGS
// ═══════════════════════════════════════════════════════════
const float    PRESSURE_LEVELS[] = { 40.0f, 70.0f, 100.0f };
const char*    PRESSURE_LABELS[] = { "LOW",  "MED",  "HIGH" };
const uint16_t TIME_OPTIONS[]    = { 10, 20, 30 };
const char*    TIME_LABELS[]     = { "10m", "20m", "30m" };

const uint8_t MODE_SEQS[4][5] = {
  { 0,1,2,3,4 },   // Mode 1: Distal → Proximal
  { 4,3,2,1,0 },   // Mode 2: Proximal → Distal
  { 0,2,4,1,3 },   // Mode 3: Alternating
  { 0,4,1,3,2 }    // Mode 4: Wave
};
const char* MODE_NAMES[] = { "DISTAL", "PROXIM", "ALTERN", "WAVE" };

uint8_t  g_pressureIdx   = 1;       // default MED
uint8_t  g_timeIdx       = 0;       // default 10 min
uint8_t  g_mode          = 0;       // default Mode 1
uint32_t g_holdMs        = 8000UL;  // inflate hold per cuff
uint32_t g_deflateWaitMs = 2000UL;  // deflate gap between cuffs

// ═══════════════════════════════════════════════════════════
//  VALVE PWM RAMP (non-blocking)
//  Fill valves: 0=off, 255=open (normally-closed)
//  Release valve: 0=open, 255=closed (normally-open, INVERTED)
// ═══════════════════════════════════════════════════════════
#define RAMP_DURATION_MS   2500UL
#define RAMP_STEPS         256
#define RAMP_STEP_INTERVAL (RAMP_DURATION_MS / RAMP_STEPS)  // ~9ms

struct ValveRamp {
  bool          active      = false;
  bool          opening     = false;
  uint8_t       duty        = 0;
  uint8_t       valveIdx    = 0;
  unsigned long lastStepTime= 0;
};
ValveRamp g_ramp;

// ═══════════════════════════════════════════════════════════
//  MOTOR SOFT START (analogWrite, non-blocking)
//  5 counts per step × 30ms = ~1.5s full ramp
// ═══════════════════════════════════════════════════════════
uint8_t       g_motorDuty    = 0;
uint8_t       g_motorTarget  = 0;
bool          g_motorRamping = false;
unsigned long g_motorRampT   = 0;

// ═══════════════════════════════════════════════════════════
//  SESSION STATE
// ═══════════════════════════════════════════════════════════
unsigned long g_sessionStartTime  = 0;
unsigned long g_sessionDurationMs = 0;
uint8_t       g_cuffStep          = 0;
bool          g_cuffInflated      = false;
unsigned long g_inflateHoldStart  = 0;
unsigned long g_deflateWaitStart  = 0;
uint8_t       g_releaseStep       = 0;
bool          g_releaseWaiting    = false;
unsigned long g_releaseStepStart  = 0;
#define RELEASE_STEP_WAIT_MS 3000UL

// ═══════════════════════════════════════════════════════════
//  BUTTONS (millis debounce, no blocking)
// ═══════════════════════════════════════════════════════════
#define DEBOUNCE_MS  50UL
#define LONGPRESS_MS 2000UL

struct Button {
  uint8_t       pin;
  bool          lastRaw        = HIGH;
  bool          state          = HIGH;
  bool          longFired      = false;
  unsigned long pressTime      = 0;
  unsigned long lastChangeTime = 0;
};
Button g_btns[4] = {{BTN_START},{BTN_MODE},{BTN_PRESS},{BTN_TIME}};
bool g_evt_start    = false;
bool g_evt_pressure = false;
bool g_evt_time     = false;
bool g_evt_mode     = false;
bool g_evt_reset    = false;

// ═══════════════════════════════════════════════════════════
//  LED PATTERNS (non-blocking)
// ═══════════════════════════════════════════════════════════
enum LedPattern { LED_OFF, LED_SOLID, LED_SLOW, LED_FAST, LED_PULSE };
LedPattern    g_ledPat    = LED_OFF;
bool          g_ledForced = false;
unsigned long g_ledTime   = 0;
bool          g_ledState  = false;
uint8_t       g_ledStep   = 0;

void setLed(LedPattern p) { if (!g_ledForced) g_ledPat = p; }

void updateLED() {
  if (g_ledForced) return;
  unsigned long now = millis();
  switch (g_ledPat) {
    case LED_OFF:   digitalWrite(LED_PIN, LOW);  break;
    case LED_SOLID: digitalWrite(LED_PIN, HIGH); break;
    case LED_SLOW:
      if (now-g_ledTime >= 1000) {
        g_ledState = !g_ledState;
        digitalWrite(LED_PIN, g_ledState);
        g_ledTime = now;
      } break;
    case LED_FAST:
      if (now-g_ledTime >= 100) {
        g_ledState = !g_ledState;
        digitalWrite(LED_PIN, g_ledState);
        g_ledTime = now;
      } break;
    case LED_PULSE:
      if (now-g_ledTime >= 80) {
        g_ledTime = now;
        g_ledStep = (g_ledStep + 1) % 25;
        digitalWrite(LED_PIN, (g_ledStep==0 || g_ledStep==2));
      } break;
  }
}

// ═══════════════════════════════════════════════════════════
//  BATTERY (GPIO 15, 4-bar display)
// ═══════════════════════════════════════════════════════════
float   g_battV    = 4.2f;
uint8_t g_battPct  = 100;
uint8_t g_battBars = 4;
unsigned long g_lastBattTime = 0;
#define BATT_INTERVAL_MS 10000UL

void readBattery() {
  uint32_t sum = 0;
  for (uint8_t i=0; i<8; i++) { sum += analogRead(BATT_PIN); delay(2); }
  float raw = sum / 8.0f;
  float v   = (raw / 4095.0f) * 3.3f * BATT_DIVIDER;
  g_battV   = v;
  float pct = (v - BATT_MIN_V) / (BATT_MAX_V - BATT_MIN_V) * 100.0f;
  g_battPct  = (uint8_t)constrain(pct, 0, 100);
  g_battBars = (g_battPct>=80)?4:(g_battPct>=55)?3:(g_battPct>=30)?2:(g_battPct>=10)?1:0;
}

// ═══════════════════════════════════════════════════════════
//  DISPLAY TIMING
// ═══════════════════════════════════════════════════════════
unsigned long g_lastDisplay  = 0;
unsigned long g_lastPressRead= 0;
#define DISPLAY_MS  250UL
#define PRESS_MS    200UL

// Boot animation
uint8_t       g_bootStep     = 0;
unsigned long g_bootStepTime = 0;
#define BOOT_STEP_MS  80UL
#define BOOT_STEPS    28

// Cuff circle animation
uint8_t       g_cuffAnim[5]  = {0,0,0,0,0};
unsigned long g_lastAnim     = 0;
#define ANIM_MS 80UL

// ═══════════════════════════════════════════════════════════
//  FORWARD DECLARATIONS
// ═══════════════════════════════════════════════════════════
void startOpenValve(uint8_t idx);
void startCloseValve(uint8_t idx);
void allValvesOff();
void setPump(bool on);
void updateMotorRamp();
float readPressure();
void startSession(); void pauseSession();
void resumeSession(); void beginRelease(); void resetSystem();
void advanceCuffStep();
void updateRamp(); void updateSession(); void updateReleaseSequence();
void pollButtons(); void handleEvents();
void updateDisplay();
void drawBootScreen(); void drawReadyScreen();
void drawRunScreen(); void drawPausedScreen(); void drawReleaseScreen();
void drawBattery4Bar(uint8_t bars);
void drawHeader(const char* label);
void drawCuffCircles();
void handleSerial(); void printHelp(); void printStatus();
void setupWiFi(); void setupServer();
void sendJSON(const char* json);
void debugValveCmd(String cmd);
void pressureStream(); void pressureTest();
void valveSweep(); void selfTest();

// ═══════════════════════════════════════════════════════════
//  EMBEDDED HTML UI (PROGMEM — no SPIFFS needed)
// ═══════════════════════════════════════════════════════════
const char HTML_UI[] PROGMEM = R"rawhtml(
<!DOCTYPE html>
<html lang="en">
<head>
<meta charset="UTF-8">
<meta name="viewport" content="width=device-width,initial-scale=1,maximum-scale=1,user-scalable=no">
<title>VerveFlo</title>
<style>
@import url('https://fonts.googleapis.com/css2?family=Rajdhani:wght@400;600;700&family=Share+Tech+Mono&display=swap');
:root{
  --bg:#070a0f;--s1:#0d1117;--s2:#111820;--border:#1a2535;
  --cyan:#00d4ff;--green:#00e5a0;--red:#ff3b5c;--amber:#ffb020;
  --purple:#8b5cf6;--text:#d8e4f0;--muted:#3d5068;
  --mono:'Share Tech Mono',monospace;--sans:'Rajdhani',sans-serif;
}
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
void loop() {
  unsigned long now = millis();

  server.handleClient();
  if (g_apMode) dnsServer.processNextRequest();
  handleSerial();

  if (now - g_lastBattTime >= BATT_INTERVAL_MS) {
    readBattery(); g_lastBattTime = now;
  }

  // Boot sequence
  if (g_sysState == STATE_BOOT) {
    if (now - g_bootStepTime >= BOOT_STEP_MS) {
      g_bootStepTime = now; g_bootStep++;
      drawBootScreen();
      if (g_bootStep >= BOOT_STEPS) {
        g_sysState = STATE_READY;
        setLed(LED_SLOW);
        Serial.println(F("[BOOT] → READY"));
      }
    }
    updateLED(); return;
  }

  if (now - g_lastPressRead >= PRESS_MS) {
    g_pressure = readPressure();
    g_lastPressRead = now;
  }

  pollButtons();
  handleEvents();
  updateRamp();
  updateMotorRamp();

  if (g_sysState == STATE_RUNNING) updateSession();
  if (g_sysState == STATE_RELEASING || g_sysState == STATE_DEFLATE_WAIT)
    updateReleaseSequence();

  // Cuff animation tick
  if (now - g_lastAnim >= ANIM_MS) {
    g_lastAnim = now;
    for (uint8_t i=0; i<5; i++) {
      if ((int)i == MODE_SEQS[g_mode][g_cuffStep] &&
          (g_sysState==STATE_RUNNING || g_sysState==STATE_DEFLATE_WAIT))
        g_cuffAnim[i] = (g_cuffAnim[i]+1) % 8;
      else
        g_cuffAnim[i] = 0;
    }
  }

  if (now - g_lastDisplay >= DISPLAY_MS) {
    updateDisplay(); g_lastDisplay = now;
  }

  updateLED();
}

// ═══════════════════════════════════════════════════════════
//  WIFI SETUP
// ═══════════════════════════════════════════════════════════
void setupWiFi() {
  prefs.begin("verveflo", false);
  g_savedSSID = prefs.getString("ssid", "");
  g_savedPass = prefs.getString("pass", "");
  prefs.end();

  // If hardcoded credentials provided, save them
  if (strlen(WIFI_SSID) > 0 && g_savedSSID.length() == 0) {
    prefs.begin("verveflo", false);
    prefs.putString("ssid", WIFI_SSID);
    prefs.putString("pass", WIFI_PASS);
    prefs.end();
    g_savedSSID = WIFI_SSID;
    g_savedPass = WIFI_PASS;
  }

  if (g_savedSSID.length() > 0) {
    Serial.printf("[WIFI] Connecting to %s\n", g_savedSSID.c_str());
    WiFi.mode(WIFI_STA);
    WiFi.begin(g_savedSSID.c_str(), g_savedPass.c_str());
    uint8_t tries = 0;
    while (WiFi.status() != WL_CONNECTED && tries < 24) {
      delay(500); Serial.print("."); tries++;
    }
    if (WiFi.status() == WL_CONNECTED) {
      g_wifiConnected = true;
      Serial.printf("\n[WIFI] Connected! Open: http://%s\n",
        WiFi.localIP().toString().c_str());
      return;
    }
    Serial.println(F("\n[WIFI] Failed → starting AP"));
  } else {
    Serial.println(F("[WIFI] No credentials → starting AP"));
  }

  // AP mode
  g_apMode = true;
  WiFi.mode(WIFI_AP);
  WiFi.softAP(AP_SSID, AP_PASS);
  IPAddress apIP(192,168,4,1);
  WiFi.softAPConfig(apIP, apIP, IPAddress(255,255,255,0));
  dnsServer.start(DNS_PORT, "*", apIP);
  Serial.printf("[WIFI] AP: %s → open 192.168.4.1\n", AP_SSID);
}

// ═══════════════════════════════════════════════════════════
//  WEBSERVER
// ═══════════════════════════════════════════════════════════
void sendJSON(const char* json) {
  server.sendHeader("Access-Control-Allow-Origin", "*");
  server.send(200, "application/json", json);
}

void setupServer() {
  server.on("/", HTTP_GET, [](){
    server.send_P(200, "text/html", HTML_UI);
  });

  // Captive portal redirects
  server.on("/generate_204",       [](){server.sendHeader("Location","http://192.168.4.1/");server.send(302);});
  server.on("/fwlink",             [](){server.sendHeader("Location","http://192.168.4.1/");server.send(302);});
  server.on("/hotspot-detect.html",[](){server.sendHeader("Location","http://192.168.4.1/");server.send(302);});

  server.on("/scan", HTTP_GET, [](){
    int n = WiFi.scanNetworks();
    String json = "[";
    for (int i=0; i<n; i++) {
      if (i>0) json += ",";
      json += "{\"ssid\":\"" + WiFi.SSID(i) + "\",\"rssi\":" + WiFi.RSSI(i) + "}";
    }
    json += "]";
    server.sendHeader("Access-Control-Allow-Origin","*");
    server.send(200,"application/json",json);
  });

  server.on("/savewifi", HTTP_GET, [](){
    if (server.hasArg("ssid") && server.hasArg("pass")) {
      prefs.begin("verveflo", false);
      prefs.putString("ssid", server.arg("ssid"));
      prefs.putString("pass", server.arg("pass"));
      prefs.end();
      sendJSON("{\"ok\":true}");
      Serial.printf("[WIFI] Saved: %s\n", server.arg("ssid").c_str());
      delay(1000); ESP.restart();
    } else sendJSON("{\"ok\":false}");
  });

  server.on("/wificlear", HTTP_GET, [](){
    prefs.begin("verveflo", false);
    prefs.remove("ssid"); prefs.remove("pass");
    prefs.end();
    sendJSON("{\"ok\":true}");
    delay(500); ESP.restart();
  });

  server.on("/status", HTTP_GET, [](){
    const char* stN[]={"BOOT","READY","RUNNING","PAUSED","RELEASING","DEFLATE_WAIT"};
    unsigned long rem=0;
    if (g_sysState==STATE_RUNNING||g_sysState==STATE_PAUSED||g_sysState==STATE_DEFLATE_WAIT){
      unsigned long el=millis()-g_sessionStartTime;
      if (el<g_sessionDurationMs) rem=(g_sessionDurationMs-el)/1000UL;
    }
    char json[320];
    snprintf(json,sizeof(json),
      "{\"state\":\"%s\",\"pressure\":%.1f,\"cuff\":%d,"
      "\"timeLeft\":%lu,\"mode\":%d,\"battery\":%d,\"battBars\":%d,"
      "\"presIdx\":%d,\"timeIdx\":%d,\"ok\":true}",
      stN[(int)g_sysState],g_pressure,g_cuffStep,
      rem,g_mode,g_battPct,g_battBars,g_pressureIdx,g_timeIdx);
    sendJSON(json);
  });

  server.on("/start",   [](){if(g_sysState==STATE_READY) startSession();  sendJSON("{\"ok\":true}");});
  server.on("/pause",   [](){
    if(g_sysState==STATE_RUNNING) pauseSession();
    else if(g_sysState==STATE_PAUSED) resumeSession();
    sendJSON("{\"ok\":true}");
  });
  server.on("/resume",  [](){if(g_sysState==STATE_PAUSED) resumeSession(); sendJSON("{\"ok\":true}");});
  server.on("/stop",    [](){beginRelease(); sendJSON("{\"ok\":true}");});
  server.on("/release", [](){beginRelease(); sendJSON("{\"ok\":true}");});

  server.on("/set_pressure",[](){
    if(server.hasArg("level")) g_pressureIdx=constrain(server.arg("level").toInt(),0,2);
    sendJSON("{\"ok\":true}");
  });
  server.on("/set_time",[](){
    if(server.hasArg("idx")) g_timeIdx=constrain(server.arg("idx").toInt(),0,2);
    sendJSON("{\"ok\":true}");
  });
  server.on("/set_mode",[](){
    if(server.hasArg("mode")) g_mode=constrain(server.arg("mode").toInt(),0,3);
    sendJSON("{\"ok\":true}");
  });
  server.on("/set_timings",[](){
    if(server.hasArg("hold_ms")) g_holdMs=constrain((uint32_t)server.arg("hold_ms").toInt(),2000UL,60000UL);
    if(server.hasArg("gap_ms"))  g_deflateWaitMs=constrain((uint32_t)server.arg("gap_ms").toInt(),1000UL,15000UL);
    sendJSON("{\"ok\":true}");
  });
  server.on("/set_custom_mode",[](){
    if(server.hasArg("seq"))
      Serial.printf("[CUSTOM] seq=%s\n", server.arg("seq").c_str());
    sendJSON("{\"ok\":true}");
  });

  server.onNotFound([](){
    if(g_apMode){ server.sendHeader("Location","http://192.168.4.1/"); server.send(302); }
    else server.send(404,"text/plain","Not found");
  });

  server.begin();
  Serial.println(F("[HTTP] Server started port 80"));
}

// ═══════════════════════════════════════════════════════════
//  BOOT SCREEN — SOLVIN logo → VerveFlo loading bar
// ═══════════════════════════════════════════════════════════
void drawBootScreen() {
  u8g2.clearBuffer();

  if (g_bootStep < 12) {
    // SOLVIN letter-by-letter reveal
    u8g2.setFont(u8g2_font_10x20_tr);
    const char* letters = "SOLVIN";
    uint8_t show = min((int)g_bootStep, 6);
    char buf[7] = {0};
    strncpy(buf, letters, show);
    uint8_t x = (128 - show * 10) / 2;
    u8g2.drawStr(x, 38, buf);
    if (g_bootStep >= 10) {
      u8g2.setFont(u8g2_font_5x7_tr);
      u8g2.drawStr(22, 52, "Medical Devices");
    }
  } else {
    // VerveFlo loading screen
    u8g2.setFont(u8g2_font_10x20_tr);
    u8g2.drawStr(14, 20, "VerveFlo");
    u8g2.setFont(u8g2_font_5x7_tr);
    u8g2.drawStr(16, 30, "Compression Therapy");

    const char* msgs[] = {
      "Initialising...  ","Calibrating...   ",
      "Loading modes... ","Connecting WiFi. ","Ready.           "
    };
    uint8_t mi = (g_bootStep<16)?0:(g_bootStep<20)?1:(g_bootStep<23)?2:(g_bootStep<26)?3:4;
    u8g2.drawStr(4, 42, msgs[mi]);

    uint8_t barFill = (uint8_t)(((g_bootStep-12)*120UL)/(BOOT_STEPS-12));
    barFill = constrain(barFill, 0, 120);
    u8g2.drawFrame(4, 48, 120, 10);
    if (barFill > 0) u8g2.drawBox(5, 49, barFill, 8);

    u8g2.setFont(u8g2_font_4x6_tr);
    if (g_wifiConnected)
      u8g2.drawStr(4, 62, WiFi.localIP().toString().c_str());
    else if (g_apMode)
      u8g2.drawStr(4, 62, "AP: VerveFlo-Setup");
  }
  u8g2.sendBuffer();
}
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

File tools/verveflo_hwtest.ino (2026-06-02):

/*
 * VerveFlo — Hardware Test
 * ESP32-S3 Dev Module · Arduino IDE · NO external libraries
 *
 * Upload this BEFORE the main firmware to verify wiring.
 * Raw bit-bang HX710B read (no Q2HX711 needed).
 *
 * BOARD SETTINGS:
 *   Board           : ESP32S3 Dev Module
 *   USB CDC On Boot : Enabled   <- MUST, else no serial
 *   Upload Speed    : 921600
 *
 * SERIAL: 115200 baud, Newline line ending
 *
 * COMMANDS:
 *   selftest   full auto test (LED, battery, pressure, pump 2s, all valves 1s)
 *   led        blink LED 5x
 *   pump on    pump motor ON          pump off   pump OFF
 *   v1..v5 on/off   fill valves
 *   vr on/off       release valve (raw HIGH/LOW — see note below)
 *   alloff     everything OFF immediately
 *   pressure   single raw read + mmHg
 *   pstream    live pressure stream + bar graph (any key stops)
 *   battery    battery raw + voltage + percent
 *   pins       print all output pin states
 *   buttons    print all button states (hold a button while typing)
 *
 * NOTE on release valve (GPIO42): it is normally-open in the real system.
 * This raw test just drives the pin HIGH/LOW so you can confirm wiring +
 * the driver. Pneumatic open/close meaning is handled in the main firmware.
 */

// ── PINS (verified hardware sheet) ───────────────
// Index: 0=Fill1, 1=Fill2, 2=Fill3, 3=Fill4, 4=Fill5, 5=Release
static const uint8_t VALVE_PINS[6] = { 26, 47, 39, 40, 41, 42 };
#define RELEASE_VALVE_IDX  5

#define PUMP_PIN     21
#define LED_PIN      3
#define HX_DATA_PIN  34   // Dout
#define HX_CLK_PIN   33   // SCK
#define BATT_ADC     15

#define BTN_START    35
#define BTN_MODE     36
#define BTN_PRESS    37
#define BTN_TIME     48

// ── Calibration (v3.1) ───────────────────────────
const float CALIB_M    = 0.00000625f;   // positive
const float CALIB_B    = 0.0f;
long        CALIB_ZERO = 8388000L;       // atmosphere ref

float    g_battV   = 0;
int      g_battPct = 0;
float    g_lastP   = 0;

// ── HX710B raw bit-bang read ─────────────────────
long readHX710B() {
  // wait until data line goes low (data ready)
  unsigned long t0 = millis();
  while (digitalRead(HX_DATA_PIN)) {
    if (millis() - t0 > 200) return -1;   // timeout
  }
  long value = 0;
  for (uint8_t i = 0; i < 24; i++) {
    digitalWrite(HX_CLK_PIN, HIGH);
    delayMicroseconds(1);
    value = (value << 1) | digitalRead(HX_DATA_PIN);
    digitalWrite(HX_CLK_PIN, LOW);
    delayMicroseconds(1);
  }
  // 25th pulse — set gain/channel
  digitalWrite(HX_CLK_PIN, HIGH);
  delayMicroseconds(1);
  digitalWrite(HX_CLK_PIN, LOW);
  // sign extend 24-bit
  if (value & 0x800000) value |= 0xFF000000;
  return value;
}

float rawToMmHg(long raw) {
  if (raw > 16000000L || raw < 0) return g_lastP;   // overflow filter
  long  adj  = raw - CALIB_ZERO;
  float mmhg = CALIB_M * (float)adj + CALIB_B;
  mmhg = constrain(mmhg, 0.0f, 250.0f);
  g_lastP = mmhg;
  return mmhg;
}

void readBattery() {
  int raw = analogRead(BATT_ADC);
  // 2S pack through divider — adjust ratio to your hardware
  g_battV   = (raw / 4095.0f) * 3.3f * 2.0f;
  g_battPct = constrain(map((int)(g_battV * 100), 600, 840, 0, 100), 0, 100);
}

// ── Valve / pump helpers ─────────────────────────
void valveWrite(uint8_t idx, bool on) {
  digitalWrite(VALVE_PINS[idx], on ? HIGH : LOW);
}

void allOff() {
  for (uint8_t i = 0; i < 6; i++) digitalWrite(VALVE_PINS[i], LOW);
  digitalWrite(PUMP_PIN, LOW);
  digitalWrite(LED_PIN, LOW);
}

// ── Self test ────────────────────────────────────
void selfTest() {
  Serial.println(F("=== SELF TEST ==="));

  Serial.print(F("LED... "));
  for (uint8_t i = 0; i < 6; i++) { digitalWrite(LED_PIN, i % 2 == 0); delay(250); }
  digitalWrite(LED_PIN, LOW);
  Serial.println(F("done"));

  readBattery();
  Serial.printf("Battery: %.2fV  %d%%\n", g_battV, g_battPct);

  long  raw  = readHX710B();
  float mmhg = rawToMmHg(raw);
  Serial.printf("Pressure: %.2f mmHg (raw=%ld)\n", mmhg, raw);

  Serial.println(F("Pump ON 2s..."));
  digitalWrite(PUMP_PIN, HIGH); delay(2000);
  digitalWrite(PUMP_PIN, LOW);

  for (uint8_t i = 0; i < 6; i++) {
    Serial.printf("Valve %d (GPIO%d) 1s...\n", i + 1, VALVE_PINS[i]);
    valveWrite(i, true);  delay(1000);
    valveWrite(i, false); delay(200);
  }
  Serial.println(F("=== SELF TEST COMPLETE ==="));
}

void printPins() {
  Serial.println(F("--- output pin states ---"));
  for (uint8_t i = 0; i < 6; i++)
    Serial.printf("Valve %d GPIO%d = %d\n", i + 1, VALVE_PINS[i], digitalRead(VALVE_PINS[i]));
  Serial.printf("Pump GPIO%d = %d\n", PUMP_PIN, digitalRead(PUMP_PIN));
  Serial.printf("LED  GPIO%d = %d\n", LED_PIN, digitalRead(LED_PIN));
}

void printButtons() {
  Serial.printf("START=%d MODE=%d PRESS=%d TIME=%d  (0=pressed, active LOW)\n",
    digitalRead(BTN_START), digitalRead(BTN_MODE),
    digitalRead(BTN_PRESS), digitalRead(BTN_TIME));
}

void pstream() {
  Serial.println(F("Live pressure (send any char to stop)..."));
  while (!Serial.available()) {
    long  raw  = readHX710B();
    float mmhg = rawToMmHg(raw);
    int   bars = constrain((int)(mmhg / 5.0f), 0, 40);
    Serial.printf("%6.1f mmHg |", mmhg);
    for (int i = 0; i < bars; i++) Serial.print('#');
    Serial.println();
    delay(200);
  }
  while (Serial.available()) Serial.read();
}

// ── Command parser ───────────────────────────────
void handleCmd(String c) {
  c.trim(); c.toLowerCase();
  if (c == "")          return;
  else if (c == "selftest") selfTest();
  else if (c == "led")  { for (uint8_t i = 0; i < 10; i++) { digitalWrite(LED_PIN, i % 2 == 0); delay(150); } digitalWrite(LED_PIN, LOW); }
  else if (c == "pump on")  { digitalWrite(PUMP_PIN, HIGH); Serial.println(F("pump ON")); }
  else if (c == "pump off") { digitalWrite(PUMP_PIN, LOW);  Serial.println(F("pump OFF")); }
  else if (c == "alloff")   { allOff(); Serial.println(F("ALL OFF")); }
  else if (c == "pressure") { long r = readHX710B(); Serial.printf("raw=%ld  %.2f mmHg\n", r, rawToMmHg(r)); }
  else if (c == "pstream")  pstream();
  else if (c == "battery")  { readBattery(); Serial.printf("%.2fV  %d%%\n", g_battV, g_battPct); }
  else if (c == "pins")     printPins();
  else if (c == "buttons")  printButtons();
  else if (c.startsWith("v") && (c.endsWith("on") || c.endsWith("off"))) {
    bool on = c.endsWith("on");
    int idx = -1;
    if (c.startsWith("vr")) idx = RELEASE_VALVE_IDX;
    else                    idx = c.charAt(1) - '1';   // v1..v5 -> 0..4
    if (idx >= 0 && idx < 6) { valveWrite(idx, on); Serial.printf("valve idx%d GPIO%d %s\n", idx, VALVE_PINS[idx], on ? "ON" : "OFF"); }
    else Serial.println(F("bad valve"));
  }
  else Serial.println(F("unknown cmd — see header for list"));
}
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
